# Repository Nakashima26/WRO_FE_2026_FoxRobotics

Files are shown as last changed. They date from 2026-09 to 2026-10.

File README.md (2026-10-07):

# WRO 2026 — Future Engineers | Self-Driving Car

> **Team:** FoxRobotics
> **| Members:** Erick Blanco · Jesse Banda · César Emiliano Ahumada
> **| Coach:** Daniel Millan
> **| Country / Region:** México — Baja California
> **| Season:** 2026

---

## Table of Contents

1. [Vehicle Overview](#1-vehicle-overview)
   - [1.1 Design goals](#11-design-goals) · [1.2 Bill of Materials](#12-bill-of-materials) · [1.3 What changed in v2](#13-what-changed-for-the-international-final-v2)
2. [Mechanical Design & Mobility](#2-mechanical-design--mobility)
   - [2.1 Chassis selection](#21-chassis-selection) · [2.2 Wheels](#22-wheels) · [2.3 Drive system (torque vs. speed)](#23-drive-system-torque-vs-speed-analysis) · [2.4 Steering](#24-steering--rack-and-pinion-with-ackermann-geometry) · [2.5 Custom parts & assembly](#25-custom-parts--assembly) · [2.6 v2 chassis](#26-v2-chassis--shorter-car-pi-on-top)
3. [Power Architecture & Sensors](#3-power-architecture--sensors)
   - [3.1 Power budget](#31-power-budget) · [3.2 Sensor selection and placement](#32-sensor-selection-and-placement) · [3.3 PCB & wiring](#33-pcb--wiring) · [3.4 Raspberry Pi 5](#34-main-computer--raspberry-pi-5-v2)
4. [Software Architecture](#4-software-architecture)
   - [4.1 System overview](#41-system-overview--two-controllers-one-link) · [4.2 Inter-controller protocol ("V2")](#42-inter-controller-protocol-v2) · [4.3 Vision pipeline](#43-vision-pipeline-raspberry-pi--pure_pursuit) · [4.4 Obstacle handling](#44-obstacle-handling-obstacle-challenge) · [4.5 ESP32 state machine](#45-esp32-finite-state-machine-srcesp32purepursuitpurepursuitino) · [4.6 Cascade PID](#46-cascade-pid-always-running-underneath) · [4.7 Startup handshake](#47-startup-handshake) · [4.8 Development status](#48-development-status)
5. [Systemic Thinking & Engineering Decisions](#5-systemic-thinking--engineering-decisions)
   - [5.0 Design constraints](#50-design-constraints) · [5.1 Subsystem interaction map](#51-subsystem-interaction-map) · [5.2 Key engineering trade-offs](#52-key-engineering-trade-offs) · [5.3 Iteration log](#53-iteration-log) · [5.4 Risk analysis](#54-risk-analysis) · [5.5 Failure & Incident log](#55-failure--incident-log)
6. [Testing & Validation](#6-testing--validation)
   - [6.1 How we test](#61-how-we-test) · [6.2 Results to date](#62-results-to-date) · [6.3 Validation matrix](#63-validation-matrix) · [6.4 Pre-run checklist](#64-pre-run-checklist-each-venue) · [6.5 Milestones](#65-milestones) · [6.6 Releases](#66-releases)
7. [How to Build & Run](#7-how-to-build--run)
   - [7.1 Hardware](#71-hardware-requirements) · [7.2 ESP32 firmware](#72-esp32-firmware) · [7.3 Raspberry Pi software](#73-raspberry-pi-software) · [7.4 Calibration](#74-calibration-before-each-venue) · [7.5 Run](#75-run) · [7.6 Autostart & deployment](#76-autostart--deployment)
8. [Repository Structure](#8-repository-structure)
9. [Videos](#9-videos)
10. [Photos](#10-photos)

**Companion document:** [Engineering Journal](ENGINEERING_JOURNAL.md) — the dated, phase-by-phase build log, from the pre-repo design work through today, tied to commits. [§5.3 Iteration log](#53-iteration-log) and [§6.5 Milestones](#65-milestones) are the thematic views of the same history.

---

# 1. Vehicle Overview

<p align="center">
  Isometric view of the vehicle
</p>

Our vehicle is a custom-built autonomous car for the WRO 2026 Future Engineers — Self-Driving Cars challenge. It completes 3 laps around a randomized track, and in the Obstacle Challenge it also detects and correctly passes coloured traffic-sign pillars (**red → keep the pillar on the car's left / pass on its right; green → keep it on the right / pass on its left**) before parking at the end.

The car uses **two controllers working together**: a Raspberry Pi runs the camera vision pipeline (a Raspberry Pi 4 at the national final, a Raspberry Pi 5 for the international final) and the high-level path planner (Pure Pursuit), and an ESP32 runs the real-time control loop, the state machine and all the actuators. They talk over a UART link with a small line-based protocol ("V2"). This split is the central architectural decision of the project and is explained in [Section 4](#4-software-architecture) and [Section 5](#5-systemic-thinking--engineering-decisions).

**Key specifications:**

| Parameter | Value |
|---|---|
| Dimensions | v1: 210 × 140 × 80 mm body, ≈240 mm overall with the extension added to drive out of the parking lot · v2: ≈170 × 130 × 110 mm (168.7 × 128 mm in CAD; height includes the camera ribbon over the top, §2.6) |
| Weight | 564 g |
| Drive type | Rear-wheel drive (RWD) |
| Steering | Ackermann rack-and-pinion, SG90 servo — v2: 53° inner / 37° outer wheel at full lock, ~106% Ackermann (§2.4) |
| High-level controller | Raspberry Pi 5, 16 GB + Active Cooler (vision + Pure Pursuit) — Raspberry Pi 4 Model B until the national final (§3.4) |
| Real-time controller | ESP32 DevKit (FSM, PID, motor & sensor I/O) |
| Inter-controller link | UART @ 115200 baud, line protocol "V2" (see §4.2) |
| Vision | Raspberry Pi Camera, NoIR wide-angle lens (FOV ≈ 120°), processed at 640 × 480; custom lens-shading calibration on the Pi 5 (ERR-03) |
| Distance sensors | HC-SR04 (5V) × 3 — left, right, front — via 5V↔3.3V level shifter · v2: + VL53L1X ToF × 4, in integration (§3.2) |
| IMU | MPU-6050 (gyroscope + accelerometer) · v2: BNO085 with on-chip sensor fusion, in integration (§3.2) |
| Drive motor | v1: N20 DC gear motor (50:1) · v2: Pololu 50:1 12 V gear motor **with encoder** · + 2:1 stage → 100:1 total |
| Motor driver | TB6612FNG |
| Battery | 3S LiPo 11.1 V 2200 mAh |
| Logic power | MINI560 step-down, 5 V |

## 1.1 Design goals

One reliable vehicle that finishes **both** challenges — scoring for completing three laps consistently over completing them fast. Everything below follows from that.

- **Fixed architecture from day one: Raspberry Pi 4 + ESP32.** The Pi does *all* image processing and vision; the ESP32 does *all* peripheral I/O — both sensing and actuation. This split was decided before the first line of code and never revisited.
- **Small footprint for maneuverability.** Comfortably inside the rulebook envelope with ~10 cm of margin on width and length — the car is ≈ 20 × 10 cm, deliberately smaller than the limit so it has room to maneuver in the obstacle field.
- **Mechanically extensible.** The chassis and the PCB were designed so components could be added later without a redesign. This paid off directly: the front ultrasonic — added for the obstacle-round segmented turn (see [§4.5](#45-esp32-finite-state-machine-srcesp32purepursuitpurepursuitino)) — went from idea to mounted-and-wired in under 30 minutes because both the chassis and the PCB already had the space and a spare header.
- **Tight-turn capable.** Rack-and-pinion steering driving both wheels symmetrically ([§2.4](#24-steering--rack-and-pinion-with-ackermann-geometry)) so the car can take the obstacle-round corners without a multi-point turn.
- **Room for a printed differential** so the rear wheels can turn at different speeds through a corner without scrub.
- **Electronics-first packaging.** The chassis was sized around the electronics — the Raspberry Pi 4 above all — and the PCB was then laid out to fit the finished mechanical model, not the other way around.

## 1.2 Bill of Materials

### Custom Manufactured Parts

| ID | Component | Description | Quantity | Supplier | Approximate Cost |
|---|---|---|---|---|---|
| 1 | BaseChasis | Main body of the vehicle. | 1 | Custom made, 3D printed | 1.6 USD |
| 2 | TopShell | Upper part of the vehicle. | 1 | Custom made, 3D printed | 1 USD |
| 3 | Cremallera | Rack used for steering. | 1 | Custom made, 3D printed | 0.1 USD |
| 4 | ServoGearDirection | Pinion for the steering system, directly connected to the servo. | 1 | Custom made, 3D printed | 0.5 USD |
| 5 | LinkageDirection | Linkage between the rack and steering knuckle. | 2 | Custom made, 3D printed | 0.05 USD |
| 6 | SteeringKnuckle | Allows lateral wheel movement for steering. | 2 | Custom made, 3D printed | 0.15 USD |
| 7 | DCsupport | Holds the DC motor in place. | 1 | Custom made, 3D printed | 0.05 USD |
| 8 | RingDifferential | Main driven gear of the differential that transfers power to the axle assembly. | 1 | Custom made, 3D printed | 0.25 USD |
| 9 | PlanetDifferential | Allows torque distribution between both wheels while enabling different wheel speeds during turns. | 2 | Custom made, 3D printed | 0.1 USD |
| 10 | PinionDifferential | Transfers rotational motion from the motor to the differential gear system. | 1 | Custom made, 3D printed | 0.1 USD |
| 11 | SunDifferential | Transfers torque from the differential gears to the wheel axle. | 2 | Custom made, 3D printed | 0.1 USD |
| 12 | CameraBase | Holds the camera frame in place. | 1 | Custom made, 3D printed | 0.1 USD |
| 13 | CameraBack | Rear section of the camera frame. Connects to the CameraBase. | 1 | Custom made, 3D printed | 0.1 USD |
| 14 | CameraFront | Camera frame. | 1 | Custom made, 3D printed | 0.2 USD |
| 15 | UltrasonicSupport | Holds an ultrasonic sensor in place (used for the left, right and front sensors). | 3 | Custom made, 3D printed | 0.3 USD |

---

### LEGO Components

| ID | Component | Description | Quantity | Supplier | Approximate Cost |
|---|---|---|---|---|---|
| 16 | Lego 6135494 | Front wheel axle. | 2 | LEGO | 0.8 USD |
| 17 | Lego 4535768 | Rear wheel axle. | 2 | LEGO | 1 USD |
| 18 | Lego 6121485 | Reduces friction on the rear wheels. | 2 | LEGO | 0.4 USD |
| 19 | Lego 4299389 | Rim for rear wheels. | 2 | LEGO | 1.2 USD |
| 20 | Lego 4184286 | Tires for rear wheels. | 2 | LEGO | 3.5 USD |
| 21 | Lego 6251174 | Rim for front wheels. | 2 | LEGO | 1.2 USD |
| 22 | Lego 6182551 | Tires for front wheels. | 2 | LEGO | 3.82 USD |

---

### Electronics

| ID | Component | Description | Quantity | Supplier | Approximate Cost |
|---|---|---|---|---|---|
| 23 | ESP32 | Real-time controller: sensor I/O, cascade PID, finite state machine, actuator PWM. | 1 | Unit Electronics | 8 USD |
| 24 | Raspberry Pi 5 (16 GB) + Active Cooler + M.2 HAT+ | High-level controller: computer vision and Pure Pursuit path planning. Replaced the Raspberry Pi 4 (60 USD) after the national final; price includes taxes and shipping. | 1 | Official reseller | 410 USD |
| 25 | Mini560 5V | Step-down regulators. v2 uses two: one only for the Raspberry Pi 5, one for the ESP32, servo and sensors (v1 had one for everything). | 2 | Amazon | 12 USD |
| 26 | BNO085 | 9-axis IMU with on-chip sensor fusion (heading at 100 Hz). Replaced the MPU-6050 (3 USD) in v2. | 1 | Local purchase | 27 USD (500 MXN) |
| 38 | VL53L1X | Laser time-of-flight distance sensors — front, left, right and rear (v2). | 4 | Local purchase | 27 USD total (500 MXN) |
| 27 | HC-SR04 | Ultrasonic distance sensors — left, right (wall following) and front (obstacle-round cornering). | 3 | Unit Electronics | 10.5 USD |
| 28 | Level Shifter | Logic-level converter for the 5 V HC-SR04 echo lines into the 3.3 V ESP32. | 1 | Unit Electronics | 7 USD |
| 29 | Driver TB6612FNG | Motor driver controlling speed and direction of the DC drive motor. | 1 | Unit Electronics | 5 USD |
| 30 | RaspiCamera V2 | Camera module used for computer vision. Came with both ribbon cables: 15-pin for the Raspberry Pi 4 and 22-to-15-pin for the Raspberry Pi 5. | 1 | Amazon | 10 USD |
| 31 | Custom PCB | Power distribution and all signal connections. v1: single board (5 USD); v2: two-floor board, in design — price pending. | 1 | JLCPCB | 5 USD (v1) |

---

### Power System

| ID | Component | Description | Quantity | Supplier | Approximate Cost |
|---|---|---|---|---|---|
| 32 | Ovonic 2200mAh 3S | 3-cell LiPo battery powering the robot's electronics and drive system. | 1 | E-Bay | 13 USD |

---

### Actuators

| ID | Component | Description | Quantity | Supplier | Approximate Cost |
|---|---|---|---|---|---|
| 33 | Pololu 50:1 12 V gear motor with encoder | Drive motor; the encoder measures speed and distance. Replaced the N20 50:1 (6 USD) in v2. | 1 | Pololu | 20 USD |
| 34 | SG90 Servo | Micro servo motor used for steering control. | 1 | Unit Electronics | 6 USD |

---

### Fasteners

| ID | Component | Description | Quantity | Supplier | Approximate Cost |
|---|---|---|---|---|---|
| 35 | M3 Screws | Used for structural assembly and component mounting. | 23 | Local Hardware Store | 1 USD |
| 36 | M3 Nuts | Used to secure structural and electronic components. | 1 | Local Hardware Store | 0.05 USD |
| 37 | M2 Nuts | Used to secure servo motor and servo pinion | 3 | Local Hardware Store | 0.15 USD |

### Total Estimated Cost

| Version | Total |
|---|---|
| v1 — national final | ~155 USD |
| v2 — international final | **~576 USD** + v2 PCB (pending) |

**Where the increase comes from:** +410 USD Raspberry Pi 5 bundle, +27 BNO085, +27 VL53L1X ×4, +20 encoder motor, +6 second regulator; −69 USD for the parts that left the car (Raspberry Pi 4, MPU-6050, N20). About 85% of the increase is the Raspberry Pi 5, justified by the profiling in [§3.4](#34-main-computer--raspberry-pi-5-v2): 40 fps vs ~15 fps, no thermal throttling.

## 1.3 What changed for the international final (v2)

After winning the national final (2026-09-19, release [`v1.0-nacional`](docs/releases.md)) we reworked the parts of the car that were limiting it. Each change has its own section with the numbers behind it.

| Area | v1 (national final) | v2 | Why | Details |
|---|---|---|---|---|
| Steering geometry | Anti-Ackermann: the outer wheel steered *more* than the inner one (39.5° inner / 42.8° outer) | Ackermann corrected: rack joints 43 → 47 mm apart, tie rods 18.13 mm | Both front wheels now roll around the same turning center instead of fighting each other | [2.4](#24-steering--rack-and-pinion-with-ackermann-geometry) |
| Steering pinion | Module 1, 14 teeth | Module 1, **19 teeth**; servo moved 2.5 mm away from the rack | Same servo travel moves the rack 36% further: ~37° → **53°** on the inner wheel (measured in CAD) | [2.4](#24-steering--rack-and-pinion-with-ackermann-geometry) |
| Main computer | Raspberry Pi 4 | **Raspberry Pi 5, 16 GB** + Active Cooler | The Pi 4 was compute-bound at 14–18 fps and hit thermal throttling at 84 °C; the Pi 5 runs the same pipeline at ~40 fps at 52 °C | [3.4](#34-main-computer--raspberry-pi-5-v2) |
| Chassis layout | ≈24 cm long; Raspberry Pi enclosed in the center; motor perpendicular to the rear axle (bevel gears) | **≈17 cm long**; battery in the center where the Pi was; Pi 5 on top, open to the air; motor parallel to the axle (spur gears, same 2:1) | Tighter turns and more room to dodge and park; the enclosed Pi overheated (84 °C, throttling) | [2.6](#26-v2-chassis--shorter-car-pi-on-top) |
| Distance sensing | 3 × HC-SR04 only | 3 × HC-SR04 **+** 4 × **VL53L1X** ToF (front, left, right, rear), cross-checked against each other | Each sensor type fails differently against the black walls: the ultrasonic gives phantom echoes, the ToF can lose a dark wall. Using both lets each one veto the other's known failure | [3.2](#why-both-ultrasonic-and-tof) |
| Drive motor | N20 50:1, open-loop | **Pololu 50:1 with encoder** (mounted; speed loop pending) | Maneuvers changed with battery voltage; the encoder gives measured speed and distance | [2.6](#26-v2-chassis--shorter-car-pi-on-top) |
| IMU | MPU-6050, gyro rate integrated on the ESP32 | **BNO085**, fused heading computed on the sensor (UART-RVC, 100 Hz) | Integrated heading was 6.5% low over a run and carried a −7.5° bias after every corner maneuver | [3.2](#bno085-imu-v2-in-integration) |
| Power | One 5 V regulator for everything | **Two** regulators: one only for the Raspberry Pi 5 | Servo current spikes must not sag the Pi's supply; the Pi 5 draws more | [3.1](#v2-power-budget) |
| PCB | One board | **Two-floor** board: power floor + logic floor (in design) | The shorter chassis has less area, and four ToF + BNO085 need new connectors | [3.3](#v2-pcb--two-floor-board-in-design) |
| Camera color | Fixed white-balance gains only (Pi 4) | Lens-shading table calibrated for our lens + gains, as a project tuning file | The new image processor of the Pi 5 showed a magenta ring at the frame edges, close to the pink parking walls and red pillars | [ERR-03](#err-03--wide-angle-noir-lens-put-a-red-cast-on-every-frame) |
| Documentation | One README | + [releases](docs/releases.md), [test record](docs/testing.md), [engineering log](docs/engineering-log.md) (ERR-10 onward) | One release per event; every failure tied to a run number and a commit | §6 |

---

# 2. Mechanical Design & Mobility

### 2.1 Chassis selection

The chassis was designed from scratch to fit all the components we needed for competition. We printed it in red and black SUNLU PLA on a Bambu Lab A1, keeping the structure as light as possible without sacrificing the rigidity the drivetrain and electronics require.

For wheel transmission shafts, we used LEGO axles throughout: part 6135494 for the front and part 4535768 for the rear. This wasn't an aesthetic choice — LEGO axles have much better dimensional consistency than fully printed shafts, which flex under load and cause alignment issues. We also added LEGO bushings (6121485) to the rear axle to cut down on friction between moving parts.

| Component | Material / Part | Purpose |
| --- | --- | --- |
| Chassis | SUNLU PLA | Main robot structure |
| Front Axles | LEGO 6135494 | Power transmission |
| Rear Axles  | LEGO 4535768 | Rear drivetrain support |
| Bushings | LEGO 6121485 | Friction reduction |
| Printer | Bambu Lab A1 | Manufacturing process |

We used PLA because it prints fast, doesn't warp like ABS, and is stiff enough for indoor competition conditions. PETG has better impact resistance and ABS handles heat better, but neither of those properties matters much for a robot running on a flat mat indoors. What did matter was being able to iterate quickly and get consistent parts, and PLA delivered on both.

### 2.2 Wheels

We tested several wheel options before settling on LEGO parts. The rear wheels use rim 4299389 with tire 4184286, and the front uses rim 6251174 with tire 6182551. Both have a 43 mm outer diameter, which keeps the ride height even front to rear.

Since the drivetrain already uses LEGO axles, LEGO-compatible rims were the obvious fit — they mount directly without adapters, which removes a potential source of wobble at the wheel interface.

The 43 mm diameter was also validated against our motor RPM target. At our gear ratio, this diameter puts normal operation in the 40–70% PWM range, which gives us enough resolution for smooth speed control. A noticeably larger wheel would push operating duty cycles above 85% and compress the usable throttle range.

We ran the car at full throttle on the competition mat surface and saw no detectable slip at the rear. The LEGO rubber compound grips the white matte WRO field without any prep needed.

### 2.3 Drive system (torque vs. speed analysis)

The main drive is an N20 DC motor with a 50:1 internal gearbox — compact at 12 × 10 × 26 mm and still enough torque for a ~1.5 kg vehicle. Between the motor output shaft and the differential, we added a 2:1 LEGO gear stage, bringing the total drivetrain reduction to **100:1** and estimated rear axle torque to about 1.76 kg·cm.

**Why 100:1 and not just 50:1?**

We ran the 50:1 configuration first. It was faster, but corner exits were inconsistent — the rear wheels would occasionally lose traction under acceleration, causing yaw disturbances the PID couldn't fully catch. At 100:1, top speed dropped but torque delivery became smooth and predictable all the way through the speed range. Corner exits became repeatable, which turned out to be a prerequisite for reliable PID tuning.

The ratio also keeps the motor in its efficient RPM band during most of the run, which matters because the motor shares a power source with the logic rail.

The car completes all three Open Challenge laps in about 12 seconds at just 60% motor speed. That headroom is useful if we need to push speed in later iterations.

**The takeaway:** we prioritized consistency over raw speed. A robot that reliably finishes 3 laps scores more than one that's faster but unpredictable.

### 2.4 Steering — rack-and-pinion with Ackermann geometry

Steering is controlled by an SG90 servo connected to both front knuckles through a rack-and-pinion mechanism with symmetric tie rods.

**Mechanism specs (v1, national final):**

| Parameter | Value |
|---|---|
| Servo | SG90 (0°–180° range) |
| Firmware straight-ahead trim | 80° (servo-horn spline offset; `centroServo` in firmware) |
| Pinion | Module 1, 14 teeth |
| Pinion pitch diameter | 14 mm (dp = m × z = 1 × 14) |
| Pinion outer diameter | 16 mm (dp + 2×addendum = 14 + 2) |
| Rack | Module 1, 11 teeth, 27.5 mm total travel |
| Rack displacement per servo degree | 0.1222 mm/° |
| Transmission ratio | 2.50° servo : 1° wheel |
| Geometric wheel steering range | ±43° from center |
| Firmware-clamped servo command | 20°–150° (≈ ±35° usable at the wheel) |

**Kinematic analysis:**

The 14 mm pitch diameter gives a pitch circumference of 43.98 mm. Each degree of servo rotation moves the rack 0.1222 mm. At 90° per side from center, the rack travels 11.00 mm per side — producing ±43° at the front wheels.

The outer diameter of 16 mm confirms the module (d_outer = dp + 2×m = 14 + 2 = 16 mm).

The 2.50:1 ratio reduces steering sensitivity at the wheel, which gives the inner control loop finer resolution at its update rate. A lower ratio would make steering response too abrupt.

The firmware never commands the full mechanical range: `escribirServo()` is clamped to 20°–150° (about ±35° at the wheel) so a saturated control output can't drive the rack into its physical end stop. That still clears the tightest Open-Challenge corridor (600 mm) and the maneuvering the Obstacle Challenge needs.

**Why rack-and-pinion over a direct servo arm?**

A direct arm only controls one wheel directly. The opposite knuckle, linked by a fixed-length tie rod, gets an angle that's geometrically correct only at center — producing toe error everywhere else. The rack pushes both tie rods symmetrically, so both wheels get the right angle at every steering position. Combined with the Ackermann geometry of the knuckles, each wheel tracks its own correct turning radius. No lateral scrub, and steering response is linear across the full range.

#### v2 redesign (October 2026) — Ackermann fix and a bigger pinion

In v2 we redesigned this mechanism because of two problems: the geometry was **anti-Ackermann**, and the car **could not turn tightly enough**. We simulated the linkage in Python with the exact CAD dimensions (the model matched the CAD within ~1°) before reprinting anything.

**Geometry reference** (top view, wheels straight, measured in SolidWorks):

| Parameter | Value |
|---|---|
| Kingpin track T (distance between the two knuckle pivots) | 60 mm |
| Wheelbase L (front kingpin line → rear axle) | 112.85 mm |
| Knuckle steering arm (pivot → tie-rod joint) | 12.49 mm, pointing ~43° outward and backward |
| Rack joints behind the kingpin line | 18.94 mm |
| Servo swing actually used | ±71° (measured from the rack travel, not the nominal ±90°) |

##### Problem 1 — anti-Ackermann (fixed)

In a turn, the inner wheel follows a smaller circle than the outer wheel, so it must steer **more**. Correct (100%) Ackermann is reached when

  **cot(δ_outer) − cot(δ_inner) = T / L = 0.532**

and the axis lines of both front wheels cross on the rear axle line.

In v1 the rack joints were only 28.5 mm apart with 26 mm tie rods. We simulated the linkage in Python with the exact CAD dimensions, and the model matched the CAD within ~1°. At full travel the car steered **39.5° on the inner wheel and 42.8° on the outer wheel**: the outer wheel was steering *more* than the inner one. The two front wheels were trying to turn around different centers, so one of them always dragged sideways. That cost traction and current in every corner, and the car turned wider than the servo command implied.

Because the knuckles had to stay as they were (a new knuckle means a new arm, and the rack position is fixed by the chassis), we only changed **the spacing between the rack joints** and **the tie-rod length**. Those two values must change together: for the wheels to point straight with the rack centered, the tie rod must be

  **linkage = √( (38.66 − spacing/2)² + 9.94² )**  (mm, center to center)

| Rack joint spacing | Tie rod | Ackermann at 30° | 40° | 45° | 50° | 55° |
|---|---|---|---|---|---|---|
| 28.5 (v1) | 26.0 | anti-Ackermann | | | | |
| 43.0 (intermediate) | 19.83 | 51% | 62% | 69% | 76% | 84% |
| **47.0 (v2)** | **18.13** | 76% | **89%** | **95%** | **102%** | 110% |
| 50.0 | 16.89 | 99% | 111% | 117% | 124% | 131% |

*(Percentage = how much of the ideal inner/outer difference the linkage achieves. Below 100% the outer wheel steers slightly too much; above 100% it steers too little.)*

**Why 47 mm:** with a fixed knuckle, Ackermann cannot be exact over the whole range, because the percentage grows as the wheels turn. We chose the spacing that is closest to 100% in the 40°–50° range, which is where the car actually turns at corners and during parking. At small angles the error is under 0.7°, so it does not matter there. Each 0.1 mm of tie-rod error toes a wheel by ~0.5°, so the printed linkages are trimmed in 0.05–0.1 mm steps until the wheels are straight.

##### Problem 2 — turning radius (bigger pinion)

The steering angle depends almost only on **how far the rack moves**, and with the v1 pinion that was **±8.7 mm**: only ~37° on the inner wheel. We looked at three options: shorter knuckle arms, moving the rack, and a bigger pinion. The bigger pinion was the only one that needed no new chassis or knuckles.

| | v1 | **v2** |
|---|---|---|
| Pinion | Module 1, 14 teeth | **Module 1, 19 teeth** (20° pressure angle) |
| Pitch / outer diameter | 14 / 16 mm | **19 / 21 mm** |
| Rack travel per servo degree | 0.122 mm/° | **0.166 mm/°** |
| Rack travel at ±71° servo | ±8.7 mm | **±11.8 mm** |
| Inner / outer wheel at full lock | ~37° / ~32° (with 43 mm spacing) | **53.1° / 37.0°** (measured in the CAD assembly; the linkage model predicted ~50° / ~37°) |
| Turning radius at the rear-axle center (L / tan δ_inner + T/2) | ~208 mm (v1: 147 mm wheelbase, 39.5°) | **~115 mm** (v2: 113 mm wheelbase) — −45% |
| Ackermann at full lock | anti-Ackermann | **~106%** (ideal outer for 53.1° inner = 37.9°, measured 37.0°) |

- **Servo position.** The pitch radius grows from 7 to 9.5 mm, so the servo axis moved **2.5 mm away from the rack** with a spacer on its mount. The rack and the tie-rod joints stay at the same height, so the linkage geometry above is not affected.
- **Pinion profile.** We generated the involute tooth profile with our own script ([`Mecanica/Engranes/gen_pinon.py`](Mecanica/Engranes/gen_pinon.py)) and exported it as a single closed DXF contour that we extrude in SolidWorks. It includes 0.10 mm of backlash for 3D printing.
- **Toggle limit.** The linkage would lock (arm and tie rod aligned) at around 16 mm of rack travel. If the servo ever reached a true ±90°, the 19-tooth pinion could push the rack to ±14.9 mm. The intended mechanical stop is the knuckle touching the chassis before that point, and the servo output is also clamped in software.
- **Servo load.** The bigger pinion needs ~1.36× more servo torque for the same rack force. It also loses some angular resolution, which is still fine for an SG90 in a 0.5 kg car. The servo must not be left stalled against the stop, because it heats up and drags down the 5 V rail.

**Servo calibration.** The servo-to-wheel relation is no longer linear: near full lock the wheels turn faster per servo degree. The servo map and the steering gains in the ESP32 firmware are recalibrated on the assembled car (pending).

### 2.5 Custom parts & assembly

Every structural part is 3D-printed in SUNLU PLA on a Bambu Lab A1. The mechanical model was built first; the PCB was then laid out to fit it. Editable SolidWorks parts are in [`models/CAD/`](models/CAD/), printable meshes in [`models/STL/`](models/STL/), isometric renders in [`models/renders/`](models/renders/).

<p align="center">
  Full vehicle CAD assembly
</p>

| Render | Part | Function / design note |
|---|---|---|
| BaseChasis render | **BaseChasis** | Main structure. Sized around the electronics (Raspberry Pi 4 first); carries the PCB, steering, drivetrain and every sensor mount. |
| TopShell render | **TopShell** | Top cover — closes the electronics bay and protects the wiring. |
| ServoGearDirection render | **ServoGearDirection** | Pinion pressed onto the SG90 output shaft — module 1, 14 teeth (19 teeth in v2, [§2.4](#24-steering--rack-and-pinion-with-ackermann-geometry); profile generated by [`Mecanica/Engranes/gen_pinon.py`](Mecanica/Engranes/gen_pinon.py)). |
| Cremallera render | **Cremallera** (rack) | Module 1, 11 teeth, 27.5 mm travel. Converts servo rotation into lateral travel for the tie rods. |
| LinkageDirection render | **LinkageDirection** ×2 | Tie rods from the rack ends to the steering knuckles — symmetric, so both wheels get the correct angle at every rack position. |
| SteeringKnuckle render | **SteeringKnuckle** ×2 | Front-wheel pivots; their geometry sets the Ackermann steering angles. |
| Differential render | **Differential** (Ring / Planet ×2 / Pinion / Sun) | Printed open differential — lets the rear wheels turn at different speeds through a corner. |
| DCsupport render | **DCsupport** | Mounts the N20 gear motor to the chassis. |
| UltrasonicSupport render | **UltrasonicSupport** ×3 | Two identical side mounts; one slightly smaller front mount, added later for the obstacle-round segmented turn. |
| Camera cage render | **CameraHold** | Structure in charge of holding the camera. Sets the fixed ~20° downward tilt the BEV homography is calibrated against ([§3.2](#32-sensor-selection-and-placement)). |

#### Assembly order

1. **Chassis base** — the reference part everything mounts to.
2. **Steering** — press the pinion onto the servo and seat the servo in the chassis; slide in the rack; link each rack end to a SteeringKnuckle with a LinkageDirection tie rod; fit the knuckles and the front LEGO axles.
3. **Drivetrain** — N20 motor into the DCsupport; assemble the printed differential; rear LEGO axles with bushings.
4. **Sensor mounts** — the two side UltrasonicSupports (identical) and the smaller front one; the camera cage (base + back + front) with the camera.
5. **Electronics** — PCB onto the chassis bosses; wire the Pi 4, ESP32, the three HC-SR04 (through the level shifter), the MPU-6050, the TB6612 + motor, the servo, and the start button + status LED.
6. **TopShell** — close the bay.

All fasteners are M3 (M2 nuts on the servo horn and pinion).

### 2.6 v2 chassis — shorter car, Pi on top

*Status: designed in SolidWorks, being printed. Final dimensions and weight will be measured on the printed car.*

For the international final we rebuilt the chassis around two problems we kept seeing at the national final:

1. **The car was long for the obstacle field.** The body was 210 mm, but it reached ≈24 cm overall with an extension we added so the car could drive out of the parking lot comfortably. At that length every dodge swept a lot of floor, and the parking maneuver had little room in the lot.
2. **The Raspberry Pi overheated.** It sat enclosed in the middle of the chassis. With the remote-view client running it reached **84 °C** and throttled its CPU ([ERR-27](docs/engineering-log.md#err-27--the-remote-desktop-client-overheated-the-pi-4)), which lowered the vision frame rate.

**What we changed**

| Change | How | Why |
|---|---|---|
| **Motor parallel to the rear axle** | The drive motor now lies along the axle and drives the differential through **spur gears** (module 1, 15-tooth pinion on the motor's D-shaft, 30-tooth ring on the differential) instead of the perpendicular bevel pair | A motor perpendicular to the axle adds its whole length to the car. Lying along the axle, it adds almost nothing. |
| **Battery in the center** | The 3S pack sits crosswise in a side-loading tunnel, in the space the Raspberry Pi used to take | The heaviest part ends up in the middle and low, which balances the load front to rear. The side tunnel makes battery swaps quick. |
| **Raspberry Pi 5 on top** | The Pi moves from the enclosed center bay to the top of the car | The Active Cooler needs free air. Enclosed, the Pi recirculated its own hot air. On top, it also stays reachable for the camera cable and the SSD. |
| **Encoder motor** | Pololu 50:1 12 V gear motor with a quadrature encoder replaces the plain N20; same 50:1 ratio | Motor speed is open-loop today, so maneuvers change with battery voltage ([ERR-11](docs/engineering-log.md#err-11--a-fresh-battery-over-rotates-the-dodges)). The encoder lets the ESP32 hold a speed and measure distance, as the rules' reference build suggests. *Mounted; firmware integration pending.* |
| **Overall length ≈24 cm → ≈17 cm** (width 128 mm) | Result of the changes above | See below |

**Why a shorter car turns tighter.** For Ackermann steering, the radius of the path at the center of the rear axle is

  **R = L / tan(δ_inner) + T/2**

where L is the wheelbase and T the kingpin track (60 mm). Shortening L shrinks R directly, at the same steering angle. With the v2 steering (53° inner wheel, [§2.4](#24-steering--rack-and-pinion-with-ackermann-geometry)) and the v2 wheelbase of **≈113 mm** (CAD), R ≈ **115 mm**. The v1 car had a wheelbase of ≈147 mm (measured) and ~40° of steering, so R ≈ **208 mm**. The turning radius is therefore **≈45% smaller**: about half from the shorter wheelbase, about half from the bigger steering angle. A smaller radius means a dodge needs less lateral room, the stop-and-turn corner maneuver needs less space ahead of the front wall, and the car fits the parking lot with more margin.

**The drivetrain keeps its ratio.** The old bevel pair was 36:18 = 2:1, and the new spur pair is 30:15 = 2:1. The total reduction stays at **100:1**, so the torque and speed analysis of [§2.3](#23-drive-system-torque-vs-speed-analysis) still holds. Spur gears are also easier to print accurately and to align than bevel gears. We checked the tooth strength with the Lewis bending equation (8 mm face, at the N20's stall torque): ≈5.7 MPa, roughly 9× below the strength of printed PLA. It is re-checked with the stall torque of the encoder motor. The gear center distance is designed at 22.6–22.7 mm (22.5 mm nominal) to leave printing clearance. The involute profiles are generated by our own script and exported as DXF; SolidWorks Standard has no gear generator.

**What stayed about the same, on purpose:** the height of the chassis, for stability in fast turns (the v2 car is ≈110 mm tall, but only the camera ribbon over the top reaches that);  the LEGO axles and wheels ([§2.1](#21-chassis-selection), [§2.2](#22-wheels)); and the camera height and angle, so the bird's-eye-view calibration concept carries over (it is re-calibrated on the new mount).

---

# 3. Power Architecture & Sensors

### 3.1 Power budget

The whole vehicle runs off an Ovonic 2200mAh 3S LiPo. Power splits two ways: the motor driver takes battery voltage directly for the DC motor, and everything else goes through a MINI560 step-down converter producing a stable 5V at up to 5A.

| Rail | Source | Consumers | Max Current Draw |
|---|---|---|---|
| 5V Logic | MINI560 Step-Down Converter | Raspberry Pi 4 + RaspiCam V2, ESP32, HC-SR04 ×3, MPU6050, SG90 | ~4.0 A |
| Battery / Main Power | Ovonic 2200mAh 3S LiPo | Entire vehicle power distribution | ~35 A discharge capability |
| Motor Power | Motor Driver directly from 3S LiPo | DC drive motor | ~1.6 A peak |
| 3.3V Internal | ESP32 internal regulator | I²C communication and internal ESP32 logic, Level Shifter | ~200 mA |

The Ovonic battery is rated 120C continuous, which is theoretically 264 A. We're drawing about 4.5 A peak — under 2% of its discharge capability. There's no shortage of headroom here.

The Raspberry Pi and the ESP32 share the 5 V rail but the DC motor is fed straight from the battery through the TB6612FNG, so stall-current spikes on the motor never sag the logic supply.

#### v2 power budget

*Design values from the component datasheets and the Raspberry Pi documentation. Each rail will be measured with an inline meter on the assembled v2 car, and the measured values will replace these.*

The Raspberry Pi 5 draws more than the Pi 4 and is sensitive to voltage drops: when its supply sags it throttles the CPU, which directly lowers the vision frame rate. We already saw this on the Pi 4 when it was fed through Dupont jumpers (`throttled=0x50005`, CPU down to 600 MHz, [ERR-08](#err-08--raspberry-pi-undervoltage-from-undersized-power-wiring)). v2 therefore has **two 5 V regulators**: one only for the Raspberry Pi 5, and one for everything else. The servo's current spikes can no longer pull down the Pi's supply.

| Rail | Load | Typical | Design peak | Basis |
|---|---|---:|---:|---|
| **5 V-A** (Mini560 #1, 5 A) | Raspberry Pi 5 under vision load | 1.5 A | 2.5 A | 0.8 A bare-board active (Raspberry Pi docs) + 4 cores busy; peak covers load spikes |
| | Camera v2 | 0.25 A | 0.25 A | Camera module figure |
| | Active Cooler fan | 0.05 A | 0.1 A | Fan at full speed above 75 °C |
| | **Rail total** | **1.8 A** | **2.85 A** | 57% of the regulator's 5 A at peak |
| **5 V-B** (Mini560 #2, 5 A) | ESP32 (radio off) | 0.08 A | 0.25 A | Datasheet |
| | SG90 servo | 0.25 A | 0.70 A | Running current; peak = stall |
| | HC-SR04 × 3 | 0.045 A | 0.045 A | 15 mA each |
| | VL53L1X × 4 | 0.08 A | 0.16 A | ~20 mA each ranging, 40 mA peak |
| | BNO085 | 0.013 A | 0.013 A | Datasheet operating figure |
| | **Rail total** | **0.47 A** | **1.17 A** | 23% of the regulator at peak |
| **Battery 11.1 V** | Drive motor via TB6612 | — | 1.6 A | Peak measured on v1 (N20); to be re-measured with the encoder motor |
| **5 V-B** | Motor encoder | 0.01 A | 0.01 A | Hall-effect encoder |

**Battery current.** With ~90% regulator efficiency, the two 5 V rails at design peak draw 5 V × (2.85 + 1.17) A / 0.9 ≈ 22 W, which is ≈2.0 A from the 11.1 V pack. Adding the motor's 1.6 A gives **≈3.6 A worst case**. The 2200 mAh pack would last over 35 minutes even at that worst case, against a 3-minute round, so **capacity is not the constraint. Voltage is.** A freshly charged pack makes the motor ~17% stronger in low-PWM maneuvers ([ERR-11](docs/engineering-log.md#err-11--a-fresh-battery-over-rotates-the-dodges)), so we race inside an 11.70–12.15 V window.

**Heat.** At its typical 1.8 A, regulator #1 loses about 1 W at 90% efficiency. It is mounted in the airflow of the Pi on top of the car.

**Check before every session:** `vcgencmd get_throttled` must read `0x0` under full vision load.

### 3.2 Sensor selection and placement

| Sensor | Purpose | Placement | Notes |
|---|---|---|---|
| Raspberry Pi Camera Module V2 | Lane, corner-line and pillar detection | Front-center, ~20° downward tilt | Main vision system, OpenCV on the Pi |
| HC-SR04 (left) | Left wall distance | Left side of the chassis | Feeds the wall-centering PID |
| HC-SR04 (right) | Right wall distance | Right side of the chassis | Feeds the wall-centering PID |
| HC-SR04 (front) | Distance to the wall ahead when approaching a corner | Front bumper, facing forward | Obstacle round only — triggers the CRUCERO → MANIOBRA sequence |
| MPU-6050 *(v1)* | Heading integration during cornering and recovery | Center of chassis | Gyro Z integrated into `anguloGyro`, echoed back to the Pi |
| BNO085 *(v2, in integration)* | Fused heading at 100 Hz | Center of chassis, near the rotation axis | Replaces the MPU-6050; heading computed on the sensor |
| VL53L1X ToF ×4 *(v2, in integration)* | Near-field distance (≤ ~80 cm) with a software-set field of view | Front, left, right and rear, ~50 mm high | Cross-checked against the HC-SR04 — see [Why both](#why-both-ultrasonic-and-tof) |

#### Camera system

The camera handles lane geometry (via a bird's-eye-view transform), the orange corner-line markers, and red/green pillar detection. Image processing runs on the Raspberry Pi (Pi 4 → Pi 5 in v2) with OpenCV in real time and drives the Pure Pursuit planner.

It is mounted front-center with a ~20° downward tilt. We tested a horizontal mount first, but that captured too much background, which slowed detection and added noise. Tilting it down focuses the field of view on the track and the obstacle zone, which cut both false positives and computational load. The exact tilt is baked into the bird's-eye-view homography during calibration (see §4.3), so the mount must not move after calibration.

The lens is a wide-angle **NoIR** unit (~120° FOV), chosen over the original ~63° lens so the camera sees far enough ahead to react to a pillar and read the corner on the same frame. The wide lens ships without an IR-cut filter, which gave the raw image a heavy red cast and broke every HSV mask. The libcamera capture pipeline pins white-balance instead of letting it float — `libcamerasrc awb-enable=false colour-gains=<1.2,1.5>` — so the correction holds across venue lighting, and the pillar HSV ranges were re-tuned on the corrected image (see [ERR-03](#err-03--wide-angle-noir-lens-put-a-red-cast-on-every-frame)).

**v2 (Raspberry Pi 5):** fixed gains alone are not enough. The lens also needs its own **lens-shading table** (ALSC), otherwise the edges of the frame turn magenta. We calibrate that table from photos of a white sheet with the official Raspberry Pi tuning tool and ship it as a project tuning file, [`src/RASPI/cam/camera_tuning/`](src/RASPI/cam/camera_tuning/README.md). Result on a white sheet: R/G and B/G = 1.00 at the center **and** at all four corners (they were 1.3–1.4 at the corners).

#### HC-SR04 ultrasonic sensors

The left and right sensors drive lateral positioning and wall following. The **front** sensor was added for the Obstacle Challenge: because that round uses a segmented, stop-and-maneuver turn instead of a continuous arc (see §4.5), the car needs to know how far it is from the wall ahead so it can decide *when* to stop cruising and *which* maneuver (forward arc or reverse pivot) to run.

We originally tested VL53L0X time-of-flight sensors. On paper they win — ±3 mm accuracy versus ±15 mm for the HC-SR04, and a narrower beam. In practice, the black competition walls absorbed their 940 nm IR signal and consistently returned out-of-range readings at 300 mm. The HC-SR04 reflects off any surface regardless of color. We went with reliability over precision and made up the accuracy difference with software filtering (EMA on all three channels, plus a 5-sample median on the front channel to reject spikes before they can trigger a maneuver).

#### MPU-6050 IMU

The MPU-6050 gives heading and rotation data during cornering and recovery. The gyro Z axis is integrated each loop into `anguloGyro`, with a 1°/s deadband to suppress MEMS thermal drift on straights. On startup the firmware averages several hundred stationary samples to compute the gyro bias (`calcGyroOffsets`); if that offset comes back unusually large the firmware halves the integration scale as a safety net. The integrated heading is also sent back to the Pi in every acknowledgement so the vision side can dead-reckon obstacle positions (see §4.4).

#### BNO085 IMU (v2, in integration)

**Why replace the MPU-6050.** The MPU-6050 only gives a gyro *rate*. The ESP32 integrates it once per main loop, with a 1°/s deadband and a bias measured at boot. Our logs show what that costs:
- The integrated heading over a full run came out **6.5% low**: ≈1010° for the 1080° of 12 corners ([§6.3](#63-validation-matrix) #6).
- After every corner maneuver the heading carried a constant **−7.5° ± 0.9°** bias ([ERR-23](docs/engineering-log.md#err-23--systematic-heading-offset-after-every-corner)).
- The integration accuracy depends on how regular the main loop is, and the loop is busy with sensors and serial traffic.

The **BNO085** is a 9-axis sensor (gyroscope, accelerometer and magnetometer) that runs the sensor fusion on its own processor, with continuous bias calibration, and outputs a finished heading.

**How we connect it.** We use its **UART-RVC** mode. The sensor sends a 19-byte packet with yaw, pitch, roll and acceleration every 10 ms (100 Hz) over a single wire: BNO TX → ESP32 GPIO 25. Each packet carries a checksum. We chose this mode because it needs no driver library, keeps the IMU off the I²C bus that the four ToF sensors share, and lets the ESP32 just read the latest heading instead of integrating it. The test sketches [`BnoRvcTest`](src/ESP32/BnoRvcTest/BnoRvcTest.ino) and [`TofBnoTest`](src/ESP32/TofBnoTest/TofBnoTest.ino) report the packet rate, the longest gap, lost packets and checksum errors.

**Acceptance before it gets control** (log-only next to the MPU-6050 first):
- ≥ 99% of packets at ~100 Hz on the car, with the motor running.
- Total rotation over 12 corners within ±1% of 1080° (the MPU-6050 was 6.5% low).
- **Heading unchanged while the motor runs at standstill.** The BNO085 includes a magnetometer, and a magnetometer sitting a few centimeters from a motor and a LiPo pack can be pulled by their magnetic fields. If this test shows drift with the motor on, we switch to the sensor's *game rotation vector* (gyro + accelerometer only, no magnetometer) over I²C, at the cost of using its driver library.

#### VL53L1X time-of-flight array (v2, in integration)

**Layout:**

| Sensor | Position | Use | XSHUT pin (ESP32) | I²C address |
|---|---|---|---|---|
| Front | Front bumper | Distance to the wall ahead: corner approach and the forward/reverse maneuver choice | GPIO 0 | 0x30 |
| Left | Left side | Distance to the side wall | GPIO 15 | 0x31 |
| Right | Right side | Distance to the side wall | GPIO 5 | 0x32 |
| Rear | Rear bumper | Reverse maneuvers: leaving the lot, reverse pivots and parking, which are blind today | GPIO 4 | 0x33 |

All four share the I²C bus (SDA 21, SCL 22) and all start at the same factory address (0x29). At boot the ESP32 holds every sensor off with its XSHUT pin, then turns them on one by one and gives each a new address. Test sketches: [`TofTest4`](src/ESP32/TofTest4/TofTest4.ino) (4 sensors), [`TofId`](src/ESP32/TofId/TofId.ino) (tells an L0X from an L1X).

#### Why both ultrasonic and ToF

The inner walls of the WRO field are **black**, and that is the hardest surface for a distance sensor. The two sensor types fail against it in **different, recognizable ways**, so we keep both and let each one catch the other's failure:

| | HC-SR04 ultrasonic | VL53L1X time-of-flight |
|---|---|---|
| Black wall | Sound reflects regardless of color ✔ | The black surface absorbs most of the 940 nm infrared. The return is weak: the reading drops out, or the range becomes wrong. Our VL53L0X lost the wall past ~70 cm ([ERR-01](#err-01--vl53l0x-lost-the-black-wall-past-70-cm)), and other teams report ~80–100 cm usable with the L1X ✘ |
| False readings | The echo returns from anything inside a wide acoustic lobe, including the side wall at a grazing angle, plus multipath reflections. The front sensor reported a wall that wasn't there in ~20% of straight-line frames ([ERR-19](docs/engineering-log.md#err-19--phantom-echoes-from-the-front-ultrasonic)) ✘ | An optical cone with no echoes. Its size is set in software (region of interest), so it can be made to look only at the wall ✔ |
| Range | Usable to ~119 cm with our timeout | Near field only (≤ ~80 cm) on a black wall |
| Speed | One ping at a time, since sensors that fire together hear each other | 20 Hz each, all four in parallel |

**Planned cross-check rule.** It runs log-only first, recorded next to the current behavior, before it gets control:
- A ToF reading counts only if its range status is valid, it is ≤ 80 cm, and it is stable for 2 readings.
- **Front:** if the two disagree by more than 15 cm and the ToF reading is valid, trust the ToF; the known failure on that side is the ultrasonic phantom. If the ToF is invalid or out of range, use the ultrasonic; the known failure there is a black-wall dropout.
- **Sides:** if the ToF says "no wall" while the ultrasonic sees one closer than 100 cm, it is a black-wall dropout, so trust the ultrasonic.
- Every disagreement is logged with both values, so the thresholds are tuned on recorded runs and not guessed.

#### Sensor placement and field geometry

Each position is chosen from the field dimensions in the rules: walls 100 mm high and black on the inside, pillars 50 × 50 × 100 mm, white floor mat.

| Sensor | Placement | Field geometry behind it |
|---|---|---|
| ToF × 4 | **~50 mm above the floor**, centered on the 100 mm wall height | The VL53L1X sees a 27° cone by default. Mounted low, that cone hits the white floor at ≈4× its mounting height, and a bright floor easily wins over a dark wall. Teams who mounted them low saw exactly this. With a **wide-and-short region of interest** (16 × 4 detector cells ≈ 27° × 7°), the vertical half-angle is ≈3.4°. At 80 cm the cone spans ±4.7 cm, so at 50 mm height it stays inside the 0–100 mm wall. |
| Ultrasonic L / R | Sides, perpendicular to the straight | They read the wall parallel to the current straight. The inside sensor reads the opening that triggers a corner. |
| Ultrasonic F + ToF F | Front bumper, on the centerline | They read the wall ahead. Their distance decides *when* the stop-and-turn starts, and *which* maneuver is used (forward arc vs reverse pivot). |
| ToF rear | Rear bumper | The parking lot and the reverse pivot happen backwards, where v1 had no sensor at all. |
| Camera | Front, ~20° down, wide-angle 120° | Sees both pillar columns of the straight and the corner line on the same frame. |
| BNO085 | Center, near the rotation axis | Keeps centripetal acceleration out of the fused heading. |

### 3.3 PCB & wiring

A custom two-layer PCB is the vehicle's backplane: it distributes power and carries every signal line between the ESP32, the sensors and the motor driver, so there is no breadboard or flying-wire harness to work loose. This is what let the front ultrasonic go in in under 30 minutes ([§1.1](#11-design-goals)) — the header was already there. The full editable KiCad project is in [`electrical/WRO_RevA/`](electrical/WRO_RevA/).

**Schematic** ([`schemes/schematic.png`](schemes/schematic.png)):

<p align="center">
  KiCad schematic
</p>

The ESP32 DevKit (`U1`) sits at the centre. Battery voltage (~11.1 V, 3S) comes in at the `VCC` screw terminal (`J1`) and splits two ways: the motor driver takes it directly, and a MINI560 buck (`V1`, bulk caps `C1`–`C4`) drops it to the 5 V logic rail. The RDB-14450 driver (`U2`) takes `PWM_MOTOR` / `AIN1` / `AIN2` from the ESP32 and drives `MOTOR_1/2` out to the screw terminal `J5`. The four HC-SR04s land on headers `US1`–`US4` (5 V / TRIG / ECHO / GND); their 5 V echo lines return through a BOB-12009 level shifter (`U3`) that steps `ECHO1`–`ECHO4` down to 3.3 V for the ESP32. The MPU-6050 (`U4`) is on I²C. The `TO_PI` header (`J3`) is the entire link to the Raspberry Pi — `RX` / `TX` for the V2 protocol, `READY` for the handshake, `PRGN` for the start button (`SW1`), plus 3.3 V / GND. Two status LEDs (`D1` PWR, `D2` READY) complete the operator interface from [§4.7](#47-startup-handshake).

**Populated board** ([`schemes/pcb_render.png`](schemes/pcb_render.png)):

<p align="center">
  3D render of the populated PCB
</p>

**Board outline** ([`electrical/PCB_dimensions.png`](electrical/PCB_dimensions.png)):

<p align="center">
  PCB outline and dimensions
</p>

The board is a custom non-rectangular shape (~55 mm at its widest) that nests into the chassis around the Raspberry Pi 4 and the drivetrain — the electronics-first packaging from [§1.1](#11-design-goals) in physical form. The cut-outs and the mounting-hole row let the PCB, the steering and the sensor mounts share one footprint without stacking height.

#### v2 PCB — two-floor board (in design)

The v1 board is a single layer of components shaped around the Raspberry Pi 4. The v2 chassis is ≈7 cm shorter, the Pi moves to the top, and the robot gains four ToF sensors (each with its own XSHUT line), the BNO085 UART and a second regulator. All of that does not fit on one footprint, so the v2 board is designed as **two stacked floors** on standoffs:

| Floor | Contents | Why separate |
|---|---|---|
| **Power** (bottom) | Battery input (XT60), switch and fuse, two Mini560 regulators (Pi / everything else), motor driver | Keeps the switching regulators and motor currents, with their heat and noise, away from the signal lines. It is also the heaviest floor, so it sits low. |
| **Logic** (top) | ESP32, level shifter, headers for 3 HC-SR04, 4 VL53L1X (I²C + XSHUT), BNO085 (UART), servo, start button and LEDs, the link to the Pi | All signal connectors on one accessible floor |

Status: schematic and layout in progress in KiCad. The v1 project in [`electrical/WRO_RevA/`](electrical/WRO_RevA/) remains the reference until RevB is fabricated. The wiring diagram will be updated with it.

### 3.4 Main computer — Raspberry Pi 5 (v2)

**Why we upgraded.** We profiled the Pi 4 running the real race code. The main Python thread was using **97% of one core**, and the loop ran at **14–18 fps** depending on the scene. Most of that time was spent on vision, not on the camera: ~5 ms capture, 17–22 ms color detection, 45–48 ms bird's-eye view and centerline. With the remote desktop client running, the Pi 4 also reached **84 °C** and entered thermal throttling. A faster CPU attacks every stage at once.

**Measured result.** We ran the unmodified race runtime on the Pi 5, replaying a recorded Obstacle Challenge run as the camera input at 30 fps:

| | Raspberry Pi 4 | Raspberry Pi 5 (16 GB) |
|---|---|---|
| Vision loop rate | ~15.5 fps (same run, recorded live) | **40–41.5 fps**, stable for 60 s |
| Time per frame | ~65 ms | ~25 ms |
| Temperature | up to 84 °C, throttled | 46 → 52 °C, no throttling (`0x0`) |

The Pi 5 also has the official **Active Cooler**. Its fan is controlled by the firmware: it stays off below 50 °C and speeds up in steps up to 100% at 75 °C. The **M.2 HAT+** is installed for a future NVMe SSD, which will mainly make storage more durable when recording a video of every run.

**What the port required:**
- **Per-frame constants.** Many filters and confirmations in the runtime count *frames* and were tuned at ~14 fps. At 40 fps they would run almost 3× faster in real time. The loop also doesn't wait for a new camera frame. Before racing on the Pi 5 we either cap the loop at the old rate or rescale those constants.
- **Serial port.** On the Pi 5, `/dev/serial0` points to the debug UART connector, not to the GPIO header. The ESP32 link uses `/dev/ttyAMA0` (GPIO 14/15).
- **GPIO.** The original `RPi.GPIO` library does not support the Pi 5, so we use the drop-in `rpi-lgpio` package and the code stays the same.
- **Camera.** The Pi 5 uses the smaller 22-pin camera connector, so the Camera v2 needs a 22-to-15-pin cable. The automatic camera detection did not recognize our module, so `/boot/firmware/config.txt` loads it explicitly (`camera_auto_detect=0`, `dtoverlay=imx219,cam1`). The capture pipeline must request `format=BGRx`; without it, the camera source fails to negotiate a format on the Pi 5's image processor (`not-negotiated`). BGRx comes straight from the image processor at 30 fps using ~2% CPU.
- **Live view without a monitor.** The remote-desktop client used on the Pi 4 does not work on the Pi 5 desktop (Wayland). [`pure_pursuit/cam_web.py`](src/RASPI/cam/pure_pursuit/cam_web.py) streams the camera (or the race HUD with `--hud`) to a browser, with the color-calibration controls.
- **OpenCV.** It must be the system package (`python3-opencv`), because the pip wheel is built without the GStreamer backend that the `libcamerasrc` capture pipeline needs.

---

# 4. Software Architecture

### 4.1 System overview — two controllers, one link

Responsibility is split across two processors by hardware strength:

```
        RASPBERRY PI 4 (Python, OpenCV)                          ESP32 (Arduino / C++)
 ┌───────────────────────────────────────────┐    V2     ┌────────────────────────────────────┐
 │ Camera → BEV homography → floor centerline│   UART    │ readPiSerial()  →  parse V2        │
 │ Pillar detection (HSV) + corner-line track│  ──────►  │                                    │
 │ Rolling obstacle memory (dead reckoning)  │  115200   │ 6-state FSM                        │
 │ Pure Pursuit geometric controller         │           │  SIGUIENDO / GIRANDO / RECUPERANDO │
 │ RECUPERANDO trigger (measured state)      │  ◄──────  │  CRUCERO / MANIOBRA / TERMINANDO   │
 │ builds one V2 line per processed frame    │  ACK:V2   │ cascade PID (wall + gyro)          │
 └───────────────────────────────────────────┘   ang=    │ servo + motor PWM, HC-SR04, MPU    │
                                               est= dir= └────────────────────────────────────┘
```

- The **Pi** decides *where to steer*: it turns the camera frame into a top-down view, extracts a drivable centerline, runs a Pure Pursuit controller against it, and reduces the result to a single normalized steering value plus a few status flags. It processes 1 of every 3 captured frames (~12–15 Hz effective).
- The **ESP32** decides *how to drive*: it owns the 50 Hz control loop, the finite state machine, corner detection, the recovery behaviour, and every actuator. In the Obstacle round it treats the Pi's steering value as the primary reference while Pure Pursuit is active, and falls back to its own wall + gyro PID if the Pi goes silent for more than 800 ms. In the Open round it ignores the Pi's steer altogether and runs on wall + gyro PID the whole time (§4.5).

Why not one processor? Real-time GPIO timing (ultrasonic pulses, servo/motor PWM, gyro sampling) and non-deterministic OpenCV latency don't coexist well on one core. Linux can't guarantee a µs-accurate pulse while an HSV pass is running; a microcontroller can't run OpenCV. Splitting them lets each run at its own natural rate, and a late UART packet just means the ESP32 reuses the last command instead of stalling. This trade-off is analyzed in [Section 5](#5-systemic-thinking--engineering-decisions).

**Where to start reading the code:** the Pi loop is [`pure_pursuit/runtime_nuevo.py`](src/RASPI/cam/pure_pursuit/runtime_nuevo.py) (`run()` → per-frame block); the ESP32 loop is [`PurePursuit.ino`](src/ESP32/PurePursuit/PurePursuit.ino) (`loop()` → the `switch (estado)`). Every module is annotated in [Section 8](#8-repository-structure); tunables live in [`pure_pursuit/config.py`](src/RASPI/cam/pure_pursuit/config.py).

### 4.2 Inter-controller protocol ("V2")

One line per processed frame, newline-terminated, 115200 baud. The rest of Section 4 refers to these fields by name.

**Pi → ESP32:**

```
V2,obs=+0.123,turn=0,state=pp,prio=1,mem=18,pp=1,pasado=0,intr=0
```

| Field | Meaning |
|---|---|
| `obs` | Normalized steering, `steer_deg / 60`, range −1…+1 (`+` = right). |
| `turn` | Legacy directional hint — always `0`; turn direction is resolved on the ESP32 side. |
| `state` | Human-readable label for the journal (e.g. `pp`, `avoid_red`). |
| `prio` | `1` = an obstacle is actively being avoided → **ESP32 must not start a corner turn**. |
| `mem` | Frames of obstacle memory still live → also blocks corner detection while `> 0`. |
| `pp` | `1` = Pure Pursuit steering is authoritative (suspend the wall PID). |
| `pasado` | One-frame pulse: the Pi confirms the car has *physically* cleared an obstacle → enter RECUPERANDO. |
| `intr` | Interior-pass flag (disabled by default). |

**ESP32 → Pi:**

```
ACK:V2,ang=12.34,est=S,dir=L,...debug...
```

| Field | Meaning |
|---|---|
| `ang` | Integrated IMU heading `anguloGyro` (degrees); resets to 0 at each turn. |
| `est` | FSM state — `S` SIGUIENDO, `G` GIRANDO **or** MANIOBRA, `R` RECUPERANDO, `C` CRUCERO. |
| `dir` | Track turn direction — `?` until the first turn, then `L` / `R`. |

### 4.3 Vision pipeline (Raspberry Pi — `pure_pursuit/`)

Entry point: `pure_pursuit/runtime_nuevo.py`. Per processed frame:

1. **Capture** — a threaded grabber pulls frames from the Pi camera through a libcamera/GStreamer pipeline at 640 × 480 BGR, dropping stale buffers so the loop always sees the newest frame.
2. **Bird's-eye view (`bev.py`)** — a homography (inverse-perspective mapping) warps the camera frame to a top-down 400 × 400 image at 2 mm/px. The homography comes from `bev_calib.npz`, generated once by `calibrate.py` from a **3 × 3 grid of 9 physical floor markers** (RANSAC fit). We use 9 points, not the minimum 4: a 4-point fit is exact and can't detect a mis-click or extrapolate safely beyond the marked area, while 9 points let the solver average out click noise across the full range the centerline actually uses (from just ahead of the car out to ~550 mm).
3. **Pillar detection (`vision.py`)** — HSV masks for red and green, then contour filtering by area, **solidity** (compact blob ≈ 0.7–0.9, painted line < 0.4) and **aspect ratio** (< 2.2) so the mat's coloured lines are not mistaken for pillars.
4. **Centerline (`centerline.py`)** — a floor-colour mask in the BEV, minus inflated "keep-out" disks around each obstacle. The keep-out is **asymmetric per the WRO rule**: a red pillar inflates further to its *left* (car passes on the right), a green pillar further to its *right*. Rows are sampled bottom-to-top; each row blends the free-gap center with the WRO pass-side using a weight that ramps up as the car nears the can (not a binary switch). A 1-D moving average plus a per-step Δx clamp keep the path within the servo's curvature limit.
5. **Pure Pursuit (`controller.py`)** — a geometric pure-pursuit controller in BEV pixel space. Look-ahead is **adaptive**: it shrinks from 100 px toward 78 px as the nearest can closes *longitudinally*, so the car keeps translating and arcs around the can instead of pivoting in place. Output is slew-limited to 6°/frame to kill frame-to-frame steering whip.
6. **Serialize** — the steering angle is normalized (`obs = steer_deg / 60`) and packed into one V2 line with the status flags (§4.2).

```mermaid
flowchart TB
    A["Capture — threaded grabber<br/>Pi camera 640×480 BGR, drops stale buffers"]
    B["BEV homography (bev.py)<br/>IPM warp to 400×400 top-down, 2 mm/px<br/>from bev_calib.npz (9-point RANSAC)"]
    C["Pillar detection (vision.py)<br/>HSV red/green + area + solidity + aspect ratio"]
    D["Centerline (centerline.py)<br/>floor mask minus asymmetric keep-out disks<br/>red inflates left, green inflates right<br/>pass-side weight ramps with distance"]
    E["Rolling obstacle memory (obstacle_memory.py)<br/>ego-motion: assumed speed + real IMU heading from ACK<br/>confidence decay, prune-on-pass"]
    F{"Measured RECUPERANDO trigger<br/>ARM / CLEAR / SKEW — see §4.4"}
    G["Pure Pursuit (controller.py)<br/>geometric, look-ahead 100 to 78 px adaptive<br/>slew-limited 6°/frame"]
    H["Serialize one V2 line<br/>obs = steer_deg / 60, plus prio / mem / pp / pasado"]
    A --> B
    B --> C
    B --> D
    C --> E
    E --> D
    E --> F
    D --> G
    G --> H
    F --> H
    H --> Z(["UART to ESP32 @ 115200"])
```

#### How the Pure Pursuit controller works

Pure Pursuit is a path-tracking method: instead of reacting to an *error signal*, the controller looks a fixed distance ahead along the path — the **look-ahead** — picks the point on the centerline at that distance, and computes the single steering angle whose turning arc, starting from the car's current pose, passes exactly through that point. Every frame the target point moves forward along the centerline and the car "chases" it, so the trajectory is always a smooth arc onto the path rather than a hand-tuned reaction curve.

```
          centerline (from BEV)                 look-ahead point picked at
        ·····•·····•·····•···•···•  ← target    distance  ld  along the path
                            ╲
                             ╲  arc the steering angle produces
              ┌───┐           ╲
              │car│────────────•   robot pose (rear axle = reference)
              └───┘
                 └─ α = bearing to target,  steer = atan2(2·L·sin α, ld)
```

Why it fits this problem:

- The vision pipeline already produces a **path** (the centerline), not a point to servo onto — Pure Pursuit consumes that path directly.
- The look-ahead is a single, physically meaningful tuning knob: **short = cut hard toward the path** (fast dodge), **long = ease onto it** (smooth cruise). That is exactly the behaviour the obstacle logic needs, so avoidance is folded into the *same* controller by shrinking the look-ahead near a can instead of adding a separate avoidance mode.
- It degrades gracefully: a noisy or short path just moves the target point a little; there is no integrator to wind up and no error term to spike.

```python
dx = target[0] - robot_x          # lateral offset to the look-ahead point (BEV px)
dy = robot_y - target[1]          # forward distance to it
ld = max(1.0, math.hypot(dx, dy)) # actual chord length
alpha     = math.atan2(dx, dy)                                   # bearing to the point
steer_rad = math.atan2(2.0 * C.WHEELBASE_PX * math.sin(alpha), ld)  # pure-pursuit arc
steer_deg = math.degrees(steer_rad)

if bev_obstacles:                                   # a can is in play
    steer_deg *= self._distance_steer_gain(...)     # ramp 0.30→1.0 as it closes
steer_deg = max(-C.MAX_STEER_DEG, min(C.MAX_STEER_DEG, steer_deg))
steer_deg = clamp(steer_deg, prev ± C.PP_STEER_SLEW_DEG)   # 6°/frame slew limit
```

`adaptive_lookahead` shrinks the look-ahead from 100 px toward 78 px, and `_distance_steer_gain` ramps the steering scale from 0.30 up to 1.0, both as the nearest can closes. Both key off the **longitudinal** distance to the can (forward gap), not the Euclidean one: a can still off to the side but level with the car used to keep those values relaxed, and the car drove straight past the point where it should have started turning. The WRO pass-side bias (right of red, left of green) is *not* handled here — it is already baked into the centerline by `centerline.py`, so the controller only has to follow the path it is given.

If `bev_calib.npz` is missing, the runtime falls back to a simple reactive PID on the pillar's x-position in the raw frame (`RED_TARGET_PX` / `GREEN_TARGET_PX`) so the car is never left without a controller.

### 4.4 Obstacle handling (Obstacle Challenge)

**Rolling obstacle memory (`obstacle_memory.py`).** The BEV only contains what the camera sees *now*; as the car closes on a can, the can leaves the bottom of the frame, its keep-out disc vanishes, and the centerline snaps back to center — cutting the corner onto the can. The memory fixes this: seen cans are stored as `(x, y, colour, confidence)` in robot-relative BEV coordinates and, every frame, the ego-motion is applied to every remembered can — forward travel from an assumed speed, rotation from the **real IMU heading change** in the ESP32 acknowledgement:

```python
dheading = heading_deg - self._prev_heading          # real Δ from the ACK, degrees
ds_px    = (C.ROBOT_SPEED_MMS * dt_s) / C.MM_PER_PX  # assumed forward advance, BEV px
# a hard dodge rotates the car without translating it — shrink ds_px when |dheading| is large
ds_px   *= turn_brake(dheading)
self._advance(ds_px, dheading)     # each can: y += ds_px, then rotate −dheading about the robot
```

Fresh detections are merged in, unseen cans decay in confidence and are pruned once genuinely passed. The inflated keep-out therefore persists until the car has physically cleared the can. The `heading_deg` this relies on is exactly the value the ESP32 integrates for its own control (see §4.6) and echoes back — one shared heading, so the map rotates by the same angle the car actually turned.

**"Mine" vs "beyond the corner" (`corner_lines.py`).** The mat's orange corner lines are tracked row-by-row in the BEV. Each remembered can is classified as *mine* (on my straight, must be avoided) or *beyond* (on the next straight, ignore for now), with asymmetric hysteresis — quick to start avoiding, slow to stop — because starting to dodge is the safe side of a wrong call.

**Far hint (`far_hint.py`).** A PD controller on a pillar's offset in the *raw* camera frame (before it projects into the BEV range) nudges the steering to pre-center on a distant can, capped at ±12° so it can only hint, never dodge.

**Mid-turn detector (`mid_turn.py`).** While the ESP32 is turning, the rolling memory is disabled (its motion model assumes forward travel, which a pivot violates). This detector instead uses only the raw per-frame BEV projections and requires a same-colour can in a consistent position across several frames inside a close forward cone to "confirm" it. **Phase 1 (current): observe and log only** — it writes `[MTURN]` lines to the journal and does not yet change steering, so we can measure its reliability on-track before wiring it into the firmware.

#### Triggering RECUPERANDO from the obstacle memory

**The problem.** When the car has to swing wide around a can with no room to spare, it finishes the pass **crooked** — pointing 30–60° off the straight — and often with one wall out of ultrasonic range. At that exact moment the camera view is the least trustworthy (the centerline is short and skewed), so letting Pure Pursuit "straighten itself" from what it sees tends to over- or under-correct into a wall. The fix is to hand the wheel to the ESP32's wall + gyro PID (state `RECUPERANDO`) until the chassis is realigned — but *only* for a hard dodge. A gentle dodge with space to spare straightens itself fine and should not stop for a recovery.

**The trigger** (`_measured_recup_trigger` in [`runtime_nuevo.py`](src/RASPI/cam/pure_pursuit/runtime_nuevo.py)) does not dead-reckon the can itself — it reads the state the obstacle memory and the IMU already provide, and needs three things to line up:

```
1. ARM   a real dodge is in progress:
         the centerline's avoidance weight near the car's axis has been
         ≥ RECUP_MEAS_ARM_W for RECUP_MEAS_ARM_FRAMES straight frames.
         On arming, snapshot heading_ref = current heading (the straight's heading).

2. CLEAR the memory no longer places any Red/Green can both far enough ahead
         of the axis AND close enough to the side to be in the way
         (going straight, the car's edge would clear it) — held for
         RECUP_MEAS_CLEAR_FRAMES frames (or just 1 if a corner is imminent).

3. SKEW  |heading − heading_ref| ≥ RECUP_MEAS_HEADING_DEG   (25°)
         → there is actually something to straighten.

ARM && CLEAR && SKEW  →  emit pasado=1  (one-frame pulse)  →  ESP32 enters RECUPERANDO
CLEAR but never SKEW for RECUP_MEAS_GENTLE_FRAMES  →  disarm quietly, no RECUPERANDO
```

```mermaid
flowchart TB
    S(["Each processed frame"]) --> ARM{"Centerline avoidance weight near the car axis<br/>>= ARM_W for ARM_FRAMES consecutive frames?"}
    ARM -- no --> S
    ARM -- yes --> SNAP["Snapshot heading_ref = current heading<br/>(the straight's heading)"]
    SNAP --> CLR{"Memory places NO red/green can both far enough ahead<br/>of the axis AND close enough to the side to be in the way?<br/>held CLEAR_FRAMES frames (or 1 if a corner is imminent)"}
    CLR -- no --> HOLD["Keep dodging (pasado = 0)"]
    HOLD --> CLR
    CLR -- yes --> SKEW{"abs(heading − heading_ref) >= 25° ?"}
    SKEW -- "yes" --> FIRE["Emit pasado = 1 (one-frame pulse)<br/>trigger disarms — fires once per dodge"]
    SKEW -- "no, for GENTLE_FRAMES" --> DIS["Disarm quietly — the gentle dodge<br/>straightens itself, no RECUPERANDO"]
    FIRE --> ESP(["ESP32: SIGUIENDO → RECUPERANDO<br/>wall + gyro PID realigns the chassis"])
```

Condition 3 is what separates the two cases: same "can is now behind me" geometry, but only the crooked one triggers a recovery. The trigger disarms on fire, so it emits **once per dodge** — a can that lingers in memory while the ESP32 straightens can't re-fire it. The can positions it checks are the same `(x, y)` the memory maintains — corrected by fresh detections while the can is visible, and carried by the *same* ego-motion the centerline uses once it isn't (see the memory snippet above) — so the trigger and the path always agree on where the can is.

This replaced an earlier approach that anchored the can's position when first seen and dead-reckoned it forward with an *assumed* speed and a bicycle model; that anchor drifted 200–400 mm within 1–2 s and fired either early (nose into the can) or far too late.

### 4.5 ESP32 finite state machine (`src/ESP32/PurePursuit/PurePursuit.ino`)

```
enum Estado { SIGUIENDO, RECUPERANDO, GIRANDO, CRUCERO, MANIOBRA, TERMINANDO, INICIO, ESTACIONANDO, ESTACIONANDO_PUNTA };
```

```mermaid
stateDiagram-v2
    [*] --> WAIT_PI: setup() blocks on READY
    WAIT_PI --> WAIT_FIRST_V2: READY acknowledged
    WAIT_FIRST_V2 --> SIGUIENDO: first V2 line (motor gated at 0 until here)

    SIGUIENDO --> RECUPERANDO: pasado=1, obstacle physically cleared [Obstacle]
    SIGUIENDO --> GIRANDO: corner detected, cooldown elapsed [Open]
    SIGUIENDO --> CRUCERO: straight clean, front sensor < FRONT_CRUCERO_CM [Obstacle]

    RECUPERANDO --> SIGUIENDO: heading settled or timeout, lane clear
    RECUPERANDO --> CRUCERO: heading settled or timeout, wall ahead [Obstacle]

    GIRANDO --> SIGUIENDO: reaches AngGiro, turn counted, heading re-zeroed
    GIRANDO --> TERMINANDO: 12th turn

    CRUCERO --> SIGUIENDO: a new "mine" obstacle appears, not yet committed
    CRUCERO --> MANIOBRA: front sensor at turn threshold (debounced), or CRUCERO timeout

    MANIOBRA --> SIGUIENDO: sub-sequence done, turn counted, new straight from 0
    MANIOBRA --> TERMINANDO: 12th turn

    TERMINANDO --> [*]: drive like SIGUIENDO for TERMINANDO_MS, then stop

    note right of MANIOBRA
      Phase machine (a motor-coast precedes every reversal — H-bridge safety):
      0 coast, 1 pivot (forward arc or reverse) to EXIT_DEG,
      2 coast, 4 straight back-off, 5 coast, then finish.
      Phase 3 = reverse stalled, coast, restart the pivot forward.
    end note
```

*This is the complete state machine as it stands on branch `SectionTurning` — the current firmware. One flag, `const bool rondaObstaculos`, selects the profile. `false` (Open Challenge): only `SIGUIENDO` / `GIRANDO` / `RECUPERANDO` / `TERMINANDO` are reachable and corners are the continuous `GIRANDO` arc. `true` (Obstacle Challenge): `GIRANDO` is replaced by the segmented `CRUCERO` → `MANIOBRA` sequence and the `pasado`-driven `RECUPERANDO` is enabled. `RECUPERANDO` never aborts on a new obstacle — it straightens the chassis first, then hands back to `SIGUIENDO`, or to `CRUCERO` if the corner is already in reach. The `main` branch still carries an earlier 3-state cut (`SIGUIENDO` / `RECUPERANDO` / `GIRANDO`); the `SectionTurning` merge is tracked as iteration log v3.0. `WAIT_PI` / `WAIT_FIRST_V2` are the startup handshake (§4.7).*

| State | Role |
|---|---|
| **SIGUIENDO** | Normal driving. In the **Obstacle round**, steering = Pi's Pure Pursuit value, blended with a light gyro correction (weight 0.12) and, only on a clean straight, the wall PID (weight 0.30). In the **Open round** the Pi's steer is ignored entirely — steering is pure wall PID + gyro PID (see §4.5.1). Watches for the next corner and for obstacle flags from the Pi. |
| **GIRANDO** | Continuous corner (**Open round only**). Servo held at full lock, motor speed ramped down in steps as `\|anguloGyro\|` grows, exits at `\|anguloGyro\| ≥ AngGiro` — **76°** in the Open round (the continuous turn coasts the rest on inertia) vs. 90° for the Obstacle round. The first corner latches the track's turn direction from whichever wall opened up. 12 corners = 3 laps → `TERMINANDO`. |
| **RECUPERANDO** | *(Obstacle round)* Entered on the Pi's `pasado=1` pulse. Vision is handed off; wall PID + gyro PID (with widened limits) straighten the chassis back into the lane. Exits when the heading error settles (with a timeout safety net for corners where one wall legitimately reads "open"). |
| **CRUCERO** | *(Obstacle round)* Straight is clean and a corner is near (front sensor < 80 cm). The car drives straight on heading toward the wall: far away, vision keeps the centerline straight; once inside `CRUCERO_GYRO_CM`, control is pure gyro + wall PID. A new obstacle sends it back to SIGUIENDO. |
| **MANIOBRA** | *(Obstacle round)* Replaces the continuous turn. At 30–60 cm from the wall a one-time decision is latched: **turn direction** = the side whose wall is open; **forward arc vs. reverse pivot** = chosen from the distance to the *outer* wall of the turn (tight against it → reverse pivot; room to swing → forward arc). A multi-phase sub-machine runs it, with motor-**coast** phases inserted between every direction reversal (plugging the H-bridge under load destroyed a TB6612 during testing). An optional short straight back-off afterward buys room on the new straight. Then it straightens, zeroes the heading for the new straight, counts the turn and returns to SIGUIENDO. |
| **TERMINANDO** | Entered automatically after the 12th turn **instead of braking on the spot**. Drives exactly like SIGUIENDO (same controller, but corner detection disabled) for `TERMINANDO_MS` (~1 s, tunable) so the car rolls forward into the start area, then cuts the motor and ends the race. Keeps the finish inside the start section instead of wherever the last corner happened to end. |

The turn-direction is latched once (all corners of a WRO track turn the same way); the forward-vs-reverse choice is made fresh at every corner from the distance to the **outer** wall of the turn ([`decidirManiobra()`](src/ESP32/PurePursuit/PurePursuit.ino)):

```cpp
// outer wall = the one that is NOT the opening (right turn → left wall, and vice-versa)
long distExt = maniobraGirarDer ? distL : distR;
maniobraReversa   = (distExt >= HUG_CM);                    // room to swing → reverse pivot
maniobraRetroceso = (distExt >  MANIOBRA_BACKOFF_MIN_CM);   // slack → short back-off after
```

**One flag switches the whole driving profile:** `const bool rondaObstaculos` at the top of `PurePursuit.ino`.

| | Open Challenge (`false`) | Obstacle Challenge (`true`) |
|---|---|---|
| Steering source | ESP32 wall PID + gyro PID **only** — the Pi's Pure Pursuit steer, `prio`/`mem`/`pasado` flags are all ignored | Pi Pure Pursuit centerline; PID as blend / fallback / RECUPERANDO |
| Corner turn | continuous `GIRANDO` | `CRUCERO` → `MANIOBRA` segmented |
| Turn target `AngGiro` | 76° (the continuous turn coasts the rest on inertia) | 90° |
| Motor PWM ceiling `MOTOR_MAX` | 180 — fast; the in-turn speed ramp does the slowing | 100 — slow, for fine maneuvers |
| `RECUPERANDO` / obstacle handling | never entered | active |

`TERMINANDO` and the cascade PID run in both.

#### 4.5.1 Open-round corner hardening

With the Pi's vision out of the loop, three guards keep the continuous turn honest:

- **`giroArmado` — corridor arm.** `detectarEsquina()` is not allowed to fire a turn until the car has first confirmed it is *inside* a corridor: both side walls < 100 cm for `PASILLO_FRAMES` (3) consecutive frames. A wide reading in the start zone therefore can't trigger a false first turn. Once armed it stays armed for the whole run, so real corners are never delayed by it (unlike a fixed time lockout).
- **Front-wall approach slow-down.** When the front sensor sees the end wall closer than `FRONT_SLOWDOWN_CM` (60 cm), speed drops to `VEL_APROX_CERRADA` (140) so `detectarEsquina()` gets a clean read of which side opens before the car is on top of the corner.
- **`marchaIniciada` timer re-anchor.** The start-guard timer (`timeStart`) is reset to the instant the car actually starts rolling — not to when `READY` arrived seconds earlier — so its window is measured from roll-off.

#### 4.5.2 States added for the national final: start from the lot and parking

The diagram above shows the six driving states. Three more were added between 2026-09-07 and the national final:

| State | Entered when | What it does |
|---|---|---|
| `INICIO` | The Pi sends `inicio=1` (the car starts inside the parking lot) | Scripted S-shaped exit from the lot, gyro-checked, then `SIGUIENDO` |
| `ESTACIONANDO` | Last corner, parking mode `PARK_PARALELO` | Parallel parking in reverse inside the magenta lot |
| `ESTACIONANDO_PUNTA` | Last corner, parking mode `PARK_PUNTA` | Simpler nose-in partial parking (fallback) |

- **Start in the lot.** While disarmed, the Pi measures the share of magenta in the frame. When the button is pressed it decides once whether the car is inside the parking lot, and sends `inicio=1` if so. The ESP32 then runs `INICIO`: it swings out of the lot, drives straight, counter-steers back to the track heading, and backs up briefly to square up before the first straight.
- **Parking.** After the last corner the car follows the outer wall. It detects the lot from the side ultrasonic profile (wall → gap → wall), and the camera confirms the magenta walls. Then it parks **in reverse** in `ESTACIONANDO`. During parking, the heading reference is re-measured against the wall to cancel the gyro drift collected over 3 laps (`PARK_TRIM_*`). Runs 1025, 1052 and 1064 produced perfect parallel parks, and we keep their constants as the reference set.

### 4.6 Cascade PID (always running underneath)

Even in Pure Pursuit mode the ESP32 computes its dual cascade PID every loop — it is the fallback, the RECUPERANDO/CRUCERO controller, and the blend term in SIGUIENDO.

```
                ┌────────────────────┐   heading    ┌────────────────────┐
  distL─distR ─►│     OUTER PID      │─ setpoint ──►│     INNER PID      │──► servo
                │   (wall centering) │              │  (heading control) │
                └────────────────────┘              └────────────────────┘
                         ▲                                    ▲
                  HC-SR04 readings                    MPU-6050 heading
```

The single-loop `error = distL − distR` controller it replaced failed past ~30° of yaw: the HC-SR04's conical beam hits the wall obliquely, both sensors over-report, the difference sits near zero while the car drifts into a wall. The outer loop turns lateral wall error into a target heading; the inner loop drives the servo to that heading using the IMU, which doesn't care about beam geometry.

**Tuned gains:** `KpWall 1.0 / KiWall 0.0 / KdWall 1.2`, `KpGyro 2.0 / KiGyro 0.0 / KdGyro 0.5`. Both integral terms are **disabled on purpose** — integral built up on long straights and released as a large steering impulse at corner entry, overshooting into the opposite wall. The derivative terms give enough steady-state correction on their own. Raw ultrasonic reads pass through an EMA filter (`alpha = 0.85`) before the PID.

```cpp
// OUTER: lateral wall error → steering contribution (Ki = 0)
errorWall  = constrain(distL - distR, -50, 50);
outputWall = KpWall*errorWall + KdWall*(errorWall - prevErrorWall)/dt;

// INNER: heading error vs. the straight's reference heading (Ki = 0)
errorGyro  = anguloObjetivo - anguloGyro;
outputGyro = KpGyro*errorGyro + KdGyro*(errorGyro - prevErrorGyro)/dt;

// SIGUIENDO with Pure Pursuit active: the Pi's steer leads, PID only trims a clean straight
servo = centroServo - (steerDeg - outputGyro*PP_GYRO_BLEND - outputWall*PP_WALL_BLEND);
// fallback / RECUPERANDO / CRUCERO-near-wall: PID alone
// servo = centroServo + (outputWall + outputGyro);
```

Heading is integrated on the ESP32 from the gyro Z axis, with the 1°/s deadband that keeps MEMS thermal noise from drifting the straight-line heading:

```cpp
float gz = mpu.getGyroZ() / gyroScale;
if (abs(gz) < 1.0) gz = 0;        // 1°/s deadband
anguloGyro += gz * dt;            // this is the value echoed back to the Pi
```

### 4.7 Startup handshake

1. Pi lights the LED on **GPIO 27** — "Pi is up".
2. Pi waits for the start button on **GPIO 17**.
3. Camera warm-up (~40 frames discarded to settle exposure).
4. Pi sends `READY` ×3; the ESP32 has been blocking in `setup()` waiting for it.
5. ESP32 replies `ACK:READY`, then **holds the motor at zero until the first real V2 line arrives** (a gate so the car never rolls forward on the fallback PID before Pure Pursuit is actually streaming). On the first frame it then rolls, `marchaIniciada` re-anchors the start-guard timer to that instant.
6. Main loop runs until 12 turns are counted, then `TERMINANDO` drives ~1 s more into the start area and stops.

```mermaid
sequenceDiagram
    participant Pi as Raspberry Pi
    participant ESP as ESP32
    Pi->>Pi: Light LED on GPIO 27 ("Pi is up")
    Pi->>Pi: Wait for start button (GPIO 17)
    Pi->>Pi: Camera warm-up (~40 frames discarded)
    Note over ESP: setup() is blocking, waiting for READY
    Pi->>ESP: READY x3
    ESP->>Pi: ACK:READY
    Note over ESP: Motor held at 0 until the first V2 line
    Pi->>ESP: First V2 line (obs + flags)
    Note over ESP: Car rolls — start-guard timer re-anchored to this instant
    loop Every processed frame (~12-15 Hz)
        Pi->>ESP: V2 line — obs, prio, mem, pp, pasado
        ESP->>Pi: ACK:V2 — ang (heading), est (S/G/R), dir (?/L/R)
    end
    Note over ESP: 12 turns counted, then roll ~1 s into start zone and stop
```

### 4.8 Development status

| Module | Challenge | Status |
|---|---|---|
| BEV homography + 9-point calibration tool | both | Complete |
| Floor centerline extraction | both | Complete |
| Pure Pursuit geometric controller | both | Complete, track-tuned |
| ESP32 cascade PID + fallback | both | Complete |
| Continuous corner turn (GIRANDO) | Open | Complete, track-tuned |
| Open-round pure-PID mode + corner hardening (`giroArmado`, approach slow-down) | Open | Implemented, not track-tuned |
| Return-to-start finish (TERMINANDO) | both | Implemented, not track-tuned |
| Pillar detection (HSV + shape filter) | Obstacle | Complete |
| Asymmetric WRO keep-out in centerline | Obstacle | Complete |
| Rolling obstacle memory (dead reckoning) | Obstacle | Complete, track-tuned |
| Corner-line "mine / beyond" classifier | Obstacle | Complete |
| Measured-state RECUPERANDO trigger | Obstacle | Complete, track-tuned |
| Segmented turn (CRUCERO → MANIOBRA) | Obstacle | Raced at the national final; forward/reverse hysteresis added after it ([ERR-22](docs/engineering-log.md#err-22--the-corner-maneuver-changed-its-mind-at-the-last-moment)) |
| Mid-turn cone detector | Obstacle | Phase 1 — logging only |
| Start from the parking lot (`INICIO`) | Obstacle | Raced at the national final |
| Parallel parking (`ESTACIONANDO`) | Obstacle | Working in testing — perfect parks in runs 1025, 1052, 1064 |
| Floor-referenced color correction + ratio tests | both | Complete ([ERR-15](docs/engineering-log.md#err-15--in-a-darker-room-the-orange-line-was-read-as-red), [ERR-17](docs/engineering-log.md#err-17--strong-light-tape-read-as-red-pale-floor-read-as-green)) |
| Raspberry Pi 5 port | both | In progress — pipeline at 40 fps on recorded video; per-frame constants pending (§3.4) |
| VL53L1X ToF sensors | both | Bench testing (§3.2) |

---

# 5. Systemic Thinking & Engineering Decisions

### 5.0 Design constraints

Every decision in this section was made inside these limits:

| Constraint | Source | Limit | How it shaped the robot |
|---|---|---|---|
| Size | Rule 11.1 | ≤ 300 × 200 × 300 mm | We stay far below it on purpose (v2 ≈17 cm long) to have room to dodge and park ([§2.6](#26-v2-chassis--shorter-car-pi-on-top)) |
| Weight | Rule 11.2 | ≤ 1.5 kg | 564 g in v1; light enough that the N20 at 100:1 accelerates cleanly |
| Drive | Rule 11.3 | One driving axle and one steering actuator; no differential drive | Ackermann rack-and-pinion + a printed rear differential |
| No radio during rounds | Rule 11.10 | Wi-Fi, Bluetooth and Tailscale must be off | All debugging is offline: a recorded video and journal per run. The live view is used only in practice |
| No manual calibration at the start | Rule 9.9 | Nothing set by hand on the table | Gyro bias measured automatically at boot; camera and color calibration done in the practice time |
| Black walls | Field rules 13.3–13.4 | Dark, IR-absorbing walls | Ultrasonic + ToF cross-check ([§3.2](#why-both-ultrasonic-and-tof)) |
| Round time and ranking | Rules 9.1, 10.7–10.8 | 3 minutes; points first, time breaks ties | Points over time: stop-and-turn corners ([§4.5](#45-esp32-finite-state-machine-srcesp32purepursuitpurepursuitino)) |
| Processing | Raspberry Pi 4 | 14–18 fps, compute-bound (97% of one core) | Raspberry Pi 5: 40 fps on the same pipeline ([§3.4](#34-main-computer--raspberry-pi-5-v2)) |
| Heat | Enclosed Pi 4 | 84 °C → thermal throttling | Pi 5 + Active Cooler, mounted on top ([§2.6](#26-v2-chassis--shorter-car-pi-on-top)) |
| Power quality | Pi undervoltage | A 0.3 V drop throttled the CPU | 22 AWG wiring; a dedicated regulator for the Pi in v2 ([§3.1](#v2-power-budget)) |
| Battery voltage | Open-loop motor (v1) | Behavior changes with charge level | Race window of 11.70–12.15 V; v2 encoder motor mounted for closed-loop speed |
| Time | Calendar | ~11 weeks between the national (09-19) and international (12-08) finals; documentation due 11-24 | Every change must be checkable on recorded runs (replay) before it gets track time |
| Budget | Team | v1 ≈155 USD; the Raspberry Pi 5 alone is ≈410 USD | The Pi 5 is the big v2 expense; the sensors were picked from the low-cost, widely documented ones (VL53L1X, BNO085) |

### 5.1 Subsystem interaction map

```mermaid
flowchart LR
    subgraph PI["Raspberry Pi 4 — vision and planning"]
        CAM["Pi camera"] --> BEV["BEV homography"]
        BEV --> PD["Pillar detection (HSV)"]
        BEV --> CL["Centerline<br/>asymmetric keep-out"]
        PD --> OM["Rolling obstacle memory"]
        OM --> CL
        OM --> TRG["RECUPERANDO trigger"]
        CL --> PP["Pure Pursuit"]
    end
    subgraph ESP["ESP32 — real-time control"]
        OUT["OUTER PID<br/>wall centering"] --> INN["INNER PID<br/>heading via IMU"]
        FSM["Finite state machine"]
        SEG["CRUCERO / MANIOBRA<br/>segmented turn"]
        INN --> ACT(["servo + motor PWM"])
        FSM --> ACT
        SEG --> ACT
    end
    USLR["HC-SR04 left / right"] --> OUT
    USF["HC-SR04 front"] --> SEG
    IMU["MPU-6050"] --> INN
    PP -- "obs (V2 @ 115200)" --> FSM
    TRG -- "prio / mem / pasado" --> FSM
    IMU -- "ACK: heading" --> OM
```

The IMU heading is the shared currency: the ESP32 integrates it for its own control *and* ships it back so the Pi's obstacle memory can rotate its map by the exact same angle. Everything the Pi decides reaches the ESP32 as four flags and one number; everything the ESP32 knows about its own state reaches the Pi as three fields. Neither side can stall the other.

### 5.2 Key engineering trade-offs

**Trade-off 1 — one processor vs. two.** One ESP32 would remove the UART protocol, the Linux boot time and the sync logic. But real-time computer vision breaks single-core timing: a 640 × 480 HSV pass is 8–15 ms on the Pi 4, and running it alongside µs-accurate GPIO pulses gives non-deterministic jitter. Splitting by hardware strength (Pi = vision + planning, ESP32 = timing + actuation) lets each run at its own rate; a delayed packet just means the ESP32 reuses the last command. The cost — a protocol to maintain and two codebases — was worth deterministic control.

**Trade-off 2 — VL53L0X ToF vs. HC-SR04 ultrasonic.** ToF wins on paper (±3 mm vs ±15 mm, narrow beam). But the WRO field's matte-black walls absorbed the 940 nm IR and returned out-of-range at 300 mm in our tests. Ultrasonic reflects off anything. We chose reliability and closed the accuracy gap with EMA filtering, a front-channel median filter, and the cascade PID.

**Trade-off 3 — reactive steering vs. geometric Pure Pursuit.** The first vision controller steered proportionally to the pillar's pixel offset. It over-reacted close in and under-reacted far out, and had no model of the car's path. Pure Pursuit against a BEV centerline gives a geometrically correct steering angle for a chosen look-ahead, and the look-ahead becomes a single tuning knob for "how hard to dodge". The cost is the BEV calibration step; the payoff is predictable arcs instead of hand-tuned reaction curves.

**Trade-off 4 — forgetting a can when it leaves the frame vs. a rolling memory.** The honest, stateless option is to only avoid what the camera sees now — but that cuts the corner onto a can the moment it drops out of view. The rolling memory keeps the keep-out alive using dead reckoning (assumed speed + real IMU rotation). The risk it adds — a "ghost" can from accumulated error — is bounded by confidence decay and a prune-on-pass rule, and is the safer failure (dodge a can that's already gone vs. clip one that's still there).

**Trade-off 5 — continuous turn vs. segmented stop-and-maneuver (Obstacle round).** A continuous 90° arc is fast and simple and works well in the Open round. In the Obstacle round, a can placed near the corner mouth turns that blind arc into a coin-flip. The `SectionTurning` design trades speed for certainty: cruise straight to a known distance from the wall (front sensor), stop, then run a deterministic maneuver — a forward arc if there's room, a reverse pivot if the car is tight against the outer wall. It is slower, but every corner becomes repeatable, which is the same principle that drove the 100:1 gear choice.

**Trade-off 6 — forward arc vs. reverse pivot inside MANIOBRA.** A forward arc needs clear space ahead to swing through; a reverse pivot needs the car close to the wall first. Rather than pick one, the firmware measures the distance to the outer wall of the turn and chooses per corner, with a reverse-timeout that bails out into a forward finish if the pivot stalls.

### 5.3 Iteration log

Structural changes and the tuning passes that revealed something — routine per-run parameter tuning in `config.py` between track sessions is not listed. Each row links to the commit that introduced the change. `Status`: **Shipped** (on `main`, track-validated) · **On branch** (implemented, still tuning) · **Superseded** (replaced by a later row) · **Reverted** (tried on track, backed out).

A dated, phase-by-phase account of the same history — including the pre-repo design and per-peripheral bring-up work — is in the [Engineering Journal](ENGINEERING_JOURNAL.md).

| Stage | Date | Change | Why it changed | Evidence | Status |
|---|---|---|---|---|---|
| Mechanical + PCB | 2026-04-13 → 04-24 | Chassis, rack-and-pinion steering, printed differential and power PCB, designed from scratch | New vehicle every season | `283078e` … `51ea239` | Shipped |
| First firmware | 2026-05-09 | Single-loop PID on `distL − distR`, VL53L0X ToF ×2, 3-state FSM (`Controller_PI.ino`) | First open-round lap | `61544cb` | Superseded |
| v1.1 — ToF → ultrasonic | 2026-05 | Both VL53L0X replaced with HC-SR04 | ToF lost the black wall past ~70 cm — [ERR-01](#err-01--vl53l0x-lost-the-black-wall-past-70-cm) | `61544cb` era | Shipped |
| v1.2 — remove the integrators | 2026-05 → 06 | `Ki = 0` on both PID loops | Integral wound up on the straights and released as one impulse at corner entry → overshoot into the far wall | `Controller_PI.ino` history | Shipped |
| v1.3 — cascade PID | 2026-05 → 06 | Outer loop (wall error → target heading) + inner loop (heading → servo, via IMU) | The `distL − distR` error goes blind past ~30° of yaw — [ERR-02](#err-02--wall-error-goes-blind-at-high-yaw) | `Controller_PI.ino` history | Shipped |
| Camera integration | 2026-05-23 | Pi camera, track-edge detection, BEV calibration tool (`calibrate.py`) | Lane geometry the ultrasonics can't see | `21fe8df`, `5797487` | Superseded |
| Two-controller split + deploy infra | 2026-06-08 → 06-09 | Pi ↔ ESP32 over UART; `wro-runtime.service`, VNC, push-to-deploy CI | OpenCV latency and µs GPIO timing can't share one core ([§5.2](#52-key-engineering-trade-offs)) | `69f82a9`, `a065d78` | Shipped |
| v2.0 — Pure Pursuit + centerline | 2026-06-13 → 06-22 | BEV homography → floor centerline → geometric Pure Pursuit (`pure_pursuit/`) | Reactive pillar-offset PID had no path model — over-reacted near, under-reacted far | `95f3744`, `e494d8c`, `556266b` | Shipped |
| Camera lens FOV 63° → 120° | 2026-07 → 08-07 | Wide-angle NoIR lens (swapped over the July break); on return, pinned white-balance (`awb-enable=false colour-gains=<1.2,1.5>`) and re-tuned the obstacle RGB ranges | Needed more forward range for the obstacle round; the wide lens has no IR-cut filter, so the raw image had a heavy red cast — [ERR-03](#err-03--wide-angle-noir-lens-put-a-red-cast-on-every-frame) | `945c2f1` | Shipped |
| v2.1 — offline sim | 2026-08-11 | Kinematic bicycle sim (`pure_pursuit_sim.py`, 520 lines) + `runtime_nuevo.py` | Tune controller logic without track time | `0a2c5d2` | Shipped |
| v2.2 — BEV calibration 4 → 9 points | 2026-08-13 | RANSAC fit over a 3×3 marker grid | A 4-point fit is exact — no way to reject a mis-click or check reprojection error | `daf1e03` | Shipped |
| v2.3 — corner-line detection | 2026-08-17 → 08-19 | Orange / blue ground-line tracking in the BEV | Turn trigger + a "my straight vs. the next one" boundary for obstacles | `d3a611e`, `8edc1b8` | Shipped |
| v2.4 — wall-aware steering (`ParedCenterline`) | 2026-08-20 → 08-21 | Centerline biased by ultrasonic wall distance; V2 protocol fixes | Centerline alone drifted toward the outer wall on wide corners | merges `f5066e1`, `24b2ec7` | Shipped |
| Open round validated | 2026-08-28 | — | 10 complete autonomous runs from varied start positions and field configs → focus moved to the Obstacle Challenge | [§6.2](#62-results-to-date) | Shipped |
| v2.5 — rolling obstacle memory | 2026-08-24 → 08-27 | Seen cans kept in a robot-relative map, advanced by assumed speed + **real IMU heading** from the ACK | Can leaves the frame → keep-out vanishes → centerline cuts the corner onto it | `a41ac0e`, `3c96abf`, `57d3218` | Shipped |
| v2.6 — hot start + run recording | 2026-08-28 | Pipeline runs disarmed during the button delay; ESP32 gated on the first V2 line; MJPG `.avi` HUD capture from button-press | Cold camera/serial cost ~2 s at the start; every run now leaves a reviewable artifact | `3245c1c`, `2355caf`, `f257371` | Shipped |
| v2.7 — undervoltage fix → frame-rate rescale | 2026-08-28 | Re-fed the Pi through 22 AWG leads (was dropping 0.3 V PCB→Pi → brown-outs, garbled frames); loop went ~7 → ~14 Hz; re-scaled every per-frame knob (slew, recovery frames, look-ahead floor) | Half the tunables were calibrated at 7 Hz and were now firing twice as fast — [ERR-08](#err-08--raspberry-pi-undervoltage-from-undersized-power-wiring) | `e4ca4f9`, `1a19cdb` | Shipped |
| v2.8 — pivot-trap root cause | 2026-08-28 → 08-29 | `LOOKAHEAD_MIN_PX` 60 → 78 (60 saturated the PP geometry); adaptive look-ahead + steer-gain re-keyed on the **longitudinal** gap; `forget_color_obstacles()` on pass so the centerline un-bends | Near a can the steer term hit ±0.9 (≈ full lock) → the car pivoted in place instead of arcing; `y` never advanced, RECUPERANDO never armed — [ERR-06](#err-06--the-car-pivoted-in-place-instead-of-arcing) | `1daf563` | Shipped |
| v2.9 — RECUPERANDO: anchor → measured state | 2026-08-28 → 08-29 | Retired the geometric dead-reckoning anchor; the trigger now reads the centerline avoidance weight, a heading snapshot, and the memory's own "is a can still in the way" test (`ARM` / `CLEAR` / `SKEW`) | The anchor integrated an *assumed* linear speed and drifted 200–400 mm in 1–2 s whenever the car had to turn hard — [ERR-07](#err-07--recuperando-trigger-tied-to-assumed-linear-speed) | `f24c547` → `25d0565` → **`52549c8`** | Shipped |
| v2.10 — turn-direction from the orange line | 2026-08-31 | Direction latched from the orange corner-line slope **during the run**, not pre-set | A pre-set direction is one more thing to get wrong at check-in | `a72a751`, `e641817` | Shipped |
| v2.11 — exterior cone at the corner mouth | 2026-08-31 | A can right at the corner: drive straight past it, *then* turn | The blind turn arc would sweep into it | `4e5ca40` | Shipped |
| v2.12 — camera-safe service restart | 2026-08-31 | CI + ops use `stop → sleep 4 → start`, never `systemctl restart` | `restart` doesn't release the CSI device — camera wedges, LED stays dark | `9aff6c9` | Shipped |
| v3.0 — segmented turns (`SectionTurning`) | 2026-09-01 | Obstacle round only: `GIRANDO` → `CRUCERO` (cruise to a set distance on the front sensor) → `MANIOBRA` (forward arc **or** reverse pivot from outer-wall distance); motor-coast phase before every direction reversal | A can at the corner mouth makes a blind 90° arc a coin-flip; a missing coast delay had already killed a driver + a motor — [ERR-04](#err-04--tb6612-and-motor-destroyed-by-a-reversal-with-no-coast-delay) | `9219f17` (+386 lines to `.ino`) | On branch |
| v3.1 — mid-turn cone detector | 2026-08-31 | `mid_turn.py` — raw per-frame BEV projections (rolling memory is off during a pivot); **Phase 1: log only** | A can first seen *during* the turn ends up beside the car afterwards → clipped | `6b0b5c7` | On branch (logging) |
| v3.2 — Open round runs pure PID | 2026-09-03 → 09-04 | Open round ignores the Pi steer — wall + gyro PID only; per-round `AngGiro` / `MOTOR_MAX`; `giroArmado` corridor-arm; front-wall approach slow-down; `TERMINANDO` finish | Open round doesn't need vision and was inheriting obstacle-round speed caps; a wide start-zone reading latched a false first turn — [ERR-05](#err-05--ultrasonic-beam-cone-bounces-off-the-corner) | `626fc91`, `13e05c1` | On branch |
| v3.3 — gyro heading-hold by default | 2026-09-05 | On a clean straight the gyro steers; vision steers only while a pillar of ours is present. `RECUPERANDO` made non-interruptible; proportional wall override (`wallPanic`) | Small dodges left the chassis 20–30° crooked and the car drifted into a wall (runs 679–690); run 700 = first clean 12-corner run | `9c4b75e` era | Shipped |
| v3.4 — start from the parking lot (`INICIO`) | 2026-09-09 | Pi measures the magenta share at the button press and sends `inicio=1`; ESP32 drives a scripted S-exit | The Obstacle Challenge may start inside the lot | `6a713e3` | Shipped |
| v3.5 — floor-referenced color correction | 2026-09-12 | Per-frame gains so the white mat matches a reference color | A darker room pushed the orange tape into the red range — [ERR-15](docs/engineering-log.md#err-15--in-a-darker-room-the-orange-line-was-read-as-red) | `7bd353f` | Shipped |
| v3.6 — camera check before arming | 2026-09-14 | Start blocked (LED off) until the camera delivers real frames | Run 860 drove 19 s with a blind camera — [ERR-12](docs/engineering-log.md#err-12--camera-blackout-mid-run) | `486cc4c` | Shipped |
| v3.7 — obstacle-memory merge guard | 2026-09-15 | A remembered pillar can't "reappear" where it physically couldn't be | Two reds across a corner merged into one (run 954) — [ERR-21](docs/engineering-log.md#err-21--two-red-signs-on-both-sides-of-a-corner-merged-into-one) | `8bfe4d0` | Shipped |
| v3.8 — red range for the new venue + B/R test | 2026-09-16 | Red hue 168–179 plus a blue/red ratio test against the pink walls | New venue: red pillars not detected at all (run 1013) — [ERR-14](docs/engineering-log.md#err-14--at-a-new-venue-red-signs-were-not-detected-at-all) | `e3784a8` | Shipped |
| v3.9 — parallel parking | 2026-09-12 → 09-17 | Lot found from the side-ultrasonic profile, reverse parallel park, heading trimmed against the wall | 15-point parking; perfect parks in runs 1025, 1052, 1064 | `cf28a0f`, `8ef47d0` | Shipped |
| **Release `v1.0-nacional`** | 2026-09-19 | Code raced at the national final — **1st place** | — | `d5cc66d` | Released |
| v3.10 — ratio tests + corner hysteresis | 2026-09-22 | `RED_GR_MAX`, `GREEN_S_MIN_MED`; forward/reverse decision with ±6 cm hysteresis | Strong light: tape read as red, floor as green (run 1190) — [ERR-17](docs/engineering-log.md#err-17--strong-light-tape-read-as-red-pale-floor-read-as-green); maneuver flip at the boundary (run 1188) — [ERR-22](docs/engineering-log.md#err-22--the-corner-maneuver-changed-its-mind-at-the-last-moment) | `96145ba` | Shipped |
| v4.0 — steering Ackermann fix + 19-tooth pinion | 2026-10-06 | Rack joints 43 → 47 mm, tie rods 18.13 mm, pinion 14 → 19 teeth | Anti-Ackermann (39.5° / 42.8°) and only ~37° of steering — [§2.4](#24-steering--rack-and-pinion-with-ackermann-geometry) | `844195e` | Validated in CAD |
| v4.1 — Raspberry Pi 5 + camera calibration | 2026-10-06 → 10-07 | Pi 5 16 GB + Active Cooler; `format=BGRx` capture; lens-shading table for our lens | Pi 4 compute-bound at 14–18 fps and throttling at 84 °C; magenta ring on the Pi 5 — [§3.4](#34-main-computer--raspberry-pi-5-v2) | `844195e` | On branch |
| v4.2 — VL53L1X ToF ×4 | 2026-10 | Front, left, right, rear on one I²C bus with XSHUT re-addressing | Front ultrasonic phantom echoes — [ERR-19](docs/engineering-log.md#err-19--phantom-echoes-from-the-front-ultrasonic) | `844195e` (test sketches) | Bench test |

### 5.4 Risk analysis

| Risk | Likelihood | Impact | Mitigation |
|---|---|---|---|
| HC-SR04 spike reading | Medium | Medium — brief PID disturbance | EMA on all channels; 5-sample median on the front channel; cascade inner loop dampens |
| Gyro drift over 3 laps | Low | Medium — heading offset grows | 1°/s deadband; heading zeroed after every turn; startup bias calibration |
| Camera mount shifts after BEV calibration | Low | High — warped top-view, wrong centerline | Rigid printed camera frame; recalibrate if the mount is touched; reprojection-error check in `calibrate.py` |
| Can leaves FOV mid-dodge → ghost obstacle | Medium | Medium — phantom keep-out | Confidence decay; prune-on-pass; memory disabled during turns |
| UART packet delayed by OpenCV load | Medium | Low — one stale command | ESP32 reuses last command; 800 ms timeout → autonomous wall+gyro fallback |
| Corner missed / mis-counted | Low | High — wrong lap count or direction | Conservative thresholds; 2 s cool-down; `prio`/`mem` block detection while dodging; front-sensor debounce in the Obstacle round |
| False first turn from a wide start-zone reading (Open round) | Medium | High — wrong direction latched for the whole run | `giroArmado`: corner detection stays disabled until both walls read < 100 cm for 3 frames; timers re-anchored to roll-off |
| MANIOBRA runs the car into the outer wall | Medium | High — DQ | Forward/reverse chosen from measured outer-wall distance; reverse-timeout fallback; optional post-maneuver back-off |
| H-bridge damage from direction reversal under load | Low (mitigated) | High — dead driver | Motor-coast phase inserted before every direction change (learned the hard way) |
| Servo driven into its end stop | Low | Low | Firmware clamps servo command to 20°–150° |

### 5.5 Failure & Incident log

Post-mortems for the failures that changed the design — what happened, the confirmed or suspected root cause, and what shipped in response. Several of these are the "learned the hard way" behind a row of the risk table in [§5.4](#54-risk-analysis).

#### ERR-01 — VL53L0X lost the black wall past 70 cm

| | |
|---|---|
| **First seen** | 2026-05, first wall-following bring-up |
| **Setup** | Two VL53L0X, one per side — the same left/right wall-distance job the HC-SR04s do now. |
| **Symptom** | Against the matte-black outer wall the effective range collapsed: past ~70 cm the sensor stopped returning correct distances. White walls read to spec. |
| **Impact** | No usable lateral reference on the black-walled portions of the track — roughly half the perimeter. |
| **Root cause** | The 940 nm IR is absorbed by the matte-black surface; too little returns for a time-of-flight solve. A single sensor on the bench reproduced it, so not a wiring or I²C fault. |
| **Fix** | Switched both channels to HC-SR04 ultrasonic (`61544cb` era) — sound reflects off any surface regardless of colour. Traded ±3 mm for ±15 mm and closed the gap in software (EMA on all channels, a 5-sample median on the front channel, the cascade PID). |
| **Status** | Resolved. Trade-off in [§5.2](#52-key-engineering-trade-offs). |

#### ERR-02 — wall error goes blind at high yaw

| | |
|---|---|
| **First seen** | 2026-05 — one of the earliest problems, open-round bring-up |
| **Symptom** | On corner entry and recovery the car kept drifting into a wall even though the PID output stayed small and stable. |
| **Root cause** | The HC-SR04's ~15° beam cone hits the wall obliquely once the chassis is yawed; both sensors over-report by similar amounts, so `distL − distR` sits near zero while the car is visibly crabbing toward one wall. This is inherent to the sensor geometry and is **still true today**. |
| **Fix** | The cascade PID stops the car *acting* on the blind error: the **outer** loop turns lateral wall error into a target heading, the **inner** loop drives the servo to that heading from the **IMU** ([§4.6](#46-cascade-pid-always-running-underneath)). At high yaw the wall term is unreliable but the inner loop is still steering on a good heading signal, so the car tracks true and re-centres once the walls read cleanly again. |
| **Status** | Mitigated by design — the sensor limitation remains; the IMU inner loop is what keeps it from mattering. This cascade is also the fallback / RECUPERANDO / CRUCERO law and the blend term in SIGUIENDO. |

#### ERR-03 — wide-angle NoIR lens put a red cast on every frame

| | |
|---|---|
| **First seen** | 2026-07, after the lens swap; corrected on return, 2026-08-07 |
| **Change that caused it** | Moved from a ~63° lens to a ~120° wide-angle lens to see far enough ahead to react to a pillar and read the corner on the same frame. The wide lens has no IR-cut filter (NoIR). |
| **Symptom** | Every frame came out heavily red-tinted. HSV masks for the floor, the orange line and the red/green pillars all broke. |
| **Root cause** | With no IR-cut filter the sensor integrates near-IR the eye doesn't see; on this sensor it lands mostly in the red channel. |
| **Fix** | Pinned the libcamera pipeline to fixed white-balance — `libcamerasrc awb-enable=false colour-gains=<1.2,1.5>` — so auto-WB can't chase the cast, then re-tuned the red/green HSV ranges on the corrected image (`945c2f1`, 2026-08-07, and the `vision.py` range passes after it). |
| **Status** | Resolved on the Pi 4. The wide FOV is now a net win — more track and obstacle zone per frame. |
| **v2 update (Raspberry Pi 5)** | The Pi 5 has a different image processor and tuning. With fixed gains only, the frame edges showed a strong **magenta ring** (corners R/G ≈ 1.31–1.40 on a white sheet). Root cause: the factory lens-shading table (ALSC) is made for the stock lens and *raises* red at the corners. Fix: new ALSC table calibrated for our lens from 5 photos of a white sheet with the official tool (`rpi-ctt`), brightness part symmetrized, shipped as [`camera_tuning/imx219_noir_wro_pi5.json`](src/RASPI/cam/camera_tuning/README.md) + gains `<1.10,1.51>`. Result: R/G and B/G = 1.00 at the center and at all corners. See [ERR-29](docs/engineering-log.md#err-29--raspberry-pi-5-magenta-ring-at-the-frame-edges). |

#### ERR-04 — TB6612 and motor destroyed by a reversal with no coast delay

| | |
|---|---|
| **First seen** | 2026-08 → 09, `SectionTurning` MANIOBRA bring-up |
| **Symptom** | While testing the maneuver, the code switched the motor from forward to reverse with no gap between the two. A current spike followed; **one TB6612 driver and one N20 motor were lost.** |
| **Root cause** | Software, not hardware: the forward → reverse transition energised the H-bridge in the opposite direction while the motor was still spinning. Back-EMF plus shoot-through current during the flip exceeded the driver's rating (classic "plugging"). |
| **Fix** | Every direction change in the firmware — forward↔reverse, in MANIOBRA and everywhere else — now passes through a mandatory motor-coast phase (`A1 = A2 = LOW`, `MANIOBRA_FRENO_MS = 300`) so the motor spins down before the opposite direction is energised (`9219f17`). |
| **Status** | Resolved. No recurrence since the coast phase went in. Risk table: "H-bridge damage from direction reversal under load". |

#### ERR-05 — ultrasonic beam cone bounces off the corner

| | |
|---|---|
| **First seen** | 2026-08, open-round corner tuning |
| **Symptom** | The car would sail past a corner opening — it "thought" it had not reached the end wall yet when it had actually passed the turn point some time earlier. |
| **Root cause** | The front HC-SR04's beam cone widens with distance; far from the end wall it catches the *corner* geometry and returns a longer bounce path, so the front distance reads larger than the true straight-ahead gap. Corner detection kept waiting. |
| **Fix** | The car slows to `VEL_APROX_CERRADA` once the front sensor drops below `FRONT_SLOWDOWN_CM` (60 cm) — more time to read *which* side opens before it is on top of the corner. Plus EMA + a 5-sample front-channel median to reject spikes, and a multi-frame confirmation before a turn is accepted. In the Obstacle round the same read drives `CRUCERO → MANIOBRA` instead of a continuous arc. |
| **Verification** | 10 complete open-round runs from varied start positions and field configurations after these changes. |
| **Status** | Resolved. |

#### ERR-06 — the car pivoted in place instead of arcing

| | |
|---|---|
| **First seen** | 2026-08-28, sessions ~orillas 414–416, right after the frame-rate doubled ([ERR-08](#err-08--raspberry-pi-undervoltage-from-undersized-power-wiring)) |
| **Symptom** | Approaching a can, the car rotated on the spot instead of driving a curve around it. The can's `y` in the BEV barely moved (≈ 40 mm/s) — turning, not translating. RECUPERANDO then never fired (the memory never saw the can go behind the axis) so the car dug deeper in. |
| **Root cause** | (1) the obstacle steer term jumped to ±0.9 — near full lock — which pivots this chassis at cruise PWM; (2) `LOOKAHEAD_MIN_PX = 60` saturated the Pure Pursuit geometry, and the adaptive look-ahead / steer-gain keyed on **Euclidean** distance, so a can level with the car but off to the side kept those relaxed and the car drove past the point it should have turned. |
| **Fix** | `LOOKAHEAD_MIN_PX` 60 → 78; adaptive look-ahead (100 → 78 px) and `_distance_steer_gain` (0.30 → 1.0) re-keyed on the **longitudinal** gap; on a confirmed pass the runtime calls `memory.forget_color_obstacles()` so the centerline un-bends and the car eases out (`1daf563`). |
| **Verification** | Session orillas 417: dodge steer ±0.4–0.7, the can's `y` advanced through the pass = arc not pivot, both cans cleared, all 12 turns completed. |
| **Status** | Resolved. |

#### ERR-07 — RECUPERANDO trigger tied to assumed linear speed

| | |
|---|---|
| **First seen** | 2026-08-28, on-track (`f24c547` geom v1, `25d0565` geom v2) |
| **Symptom** | The recover-into-lane state fired either too early — nosing into the can it was meant to have cleared — or seconds too late, after the car had already straightened badly. Worst whenever the pass needed a large heading change. |
| **Root cause** | The trigger anchored the can's position when first seen and dead-reckoned it forward using an **assumed linear speed** through a bicycle model. With no measurement feedback the anchor drifted 200–400 mm in 1–2 s, and a hard dodge — car rotating, barely translating — broke the speed assumption entirely. `SPEED_SCALE` at 1.0 / 0.35 / 0.60 were all wrong somewhere. |
| **Fix** | Retired the anchor (`52549c8`). `_measured_recup_trigger` reads state that is already measured: **ARM** when the centerline's avoidance weight near the axis has been high for several frames (snapshot the heading), **CLEAR** when the rolling memory places no can in the path, fire only if **SKEW** — `|heading − snapshot| ≥ 25°`. A gentle dodge that straightens itself never stops for a recovery. |
| **Status** | Resolved. Finding a dodge shape that armed RECUPERANDO *reliably* was the single longest debugging effort of the obstacle round. Full history in [§4.4](#44-obstacle-handling-obstacle-challenge). |

#### ERR-08 — Raspberry Pi undervoltage from undersized power wiring

| | |
|---|---|
| **First seen** | 2026-08 |
| **Symptom** | Frames processed poorly or not at all; the Pi would sometimes power off mid-run. Intermittent, load-dependent. |
| **Root cause** | ~0.3 V drop between the PCB 5 V rail and the Pi's input on undersized power leads. Under vision + steering load the Pi input sagged below its undervoltage threshold and it throttled or browned out. |
| **Fix** | Re-ran the Pi feed in 22 AWG. The rail held; the processing loop went from ~7 fps to ~14 fps. |
| **Follow-on** | The frame-rate jump then destabilised the evasion tuning — several knobs were expressed per-frame, and doubling the rate doubled their effect. Every per-frame parameter was re-scaled (iteration log v2.7); the pivot-trap ([ERR-06](#err-06--the-car-pivoted-in-place-instead-of-arcing)) surfaced in the same window. |
| **Status** | Resolved (wiring). Pi input voltage is now on the pre-run checklist. |

#### ERR-09 — separating "my straight" from "the next straight" *(open)*

| | |
|---|---|
| **First seen** | 2026-09, `SectionTurning` |
| **Symptom** | A can on the *next* straight, visible over the corner, is sometimes treated as an obstacle on the current straight (or vice-versa). Wrong classification → an unnecessary dodge, or a real can ignored. |
| **Current handling** | `corner_lines.py` tracks the orange corner line row-by-row in the BEV and labels each remembered can *mine* / *beyond* with asymmetric hysteresis (quick to start avoiding, slow to stop). Tried and reverted: locking onto the primary can by camera-bbox height (`601ea8d` … `ad4f71e`, 2026-09-02 — bbox too noisy frame to frame). |
| **Impact** | The main reason the obstacle round is not yet complete on every field configuration. Simple layouts pass reliably; a can straddling the corner sightline does not. |
| **Status** | **Open — active work.** |
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

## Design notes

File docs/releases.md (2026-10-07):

# Releases

Each competition corresponds to one release. A release is a git tag on the exact code that ran, plus these notes. To get the code of a release: `git checkout <tag>`.

| Release | Event | Date | Commit | Result |
|---|---|---|---|---|
| [`v1.0-nacional`](#v10-nacional--mexico-national-final) | WRO Mexico national final | 2026-09-19 | `d5cc66d` | 1st place, documentation 26/30 |
| [`v2.0-internacional`](#v20-internacional--in-progress) | WRO international final | 2026-12-08 to 12-10 | — | In progress |

---

## v1.0-nacional — Mexico national final

**Hardware**

| Item | Value |
|---|---|
| Main computer | Raspberry Pi 4 |
| Controller | ESP32 DevKit |
| Camera | Raspberry Pi Camera v2 + NoIR wide-angle lens (~120°), 640×480, fixed gains `<1.2,1.5>` |
| Distance | 3 × HC-SR04 (left, right, front) |
| IMU | MPU-6050 (gyro Z) |
| Drive | N20 50:1 + 2:1 gear stage, LEGO differential |
| Steering | SG90 servo, rack and pinion, 14-tooth module-1 pinion, rack joints 43 mm apart, ~37° inner wheel |

**Software**
- Vision on the Pi: floor-referenced color correction → red/green/magenta detection → bird's-eye view → corner lines → obstacle memory → corridor centerline → Pure Pursuit, at ~14–18 fps.
- ESP32 nine-state machine. Gyro heading-hold on clean straights; vision steers only while dodging.
- Obstacle Challenge: stop-and-turn corners (forward arc or reverse pivot). Open Challenge: continuous gyro-gated turn.
- Start from the parking lot (`INICIO`). Parallel parking (`ESTACIONANDO`).
- Hot start: the pipeline runs disarmed before the button, so the first sign is already tracked at the start.
- Camera brightness check before arming.

**Known issues at this release:** phantom front echoes (ERR-19); heading drift built up by dodges (ERR-23); performance depends on the battery voltage window (ERR-11); the forward/reverse decision could flip at the 28 cm boundary (ERR-22, fixed after the event).

---

## v2.0-internacional — in progress

Changes since `v1.0-nacional` (details in the [README](../README.md#13-what-changed-for-the-international-final-v2) and the [engineering log](engineering-log.md)):

| Area | Change | Status |
|---|---|---|
| Steering | Ackermann corrected (rack joints 47 mm, tie rods 18.13 mm); 19-tooth pinion; 53.1° / 37.0° at full lock | Validated in CAD; track test pending |
| Computer | Raspberry Pi 5 (16 GB) + Active Cooler; same pipeline at 40–41.5 fps | Port in progress: frame-rate constants pending |
| Sensors | 4 × VL53L1X ToF (front, left, right, rear) | Bench test |
| Vision | Ratio tests against orange tape and pale floor (`RED_GR_MAX`, `GREEN_S_MIN_MED`) | Validated (replay over 6 runs) |
| Camera | Pi 5 capture fix (`format=BGRx`) + lens-shading table for our lens + gains `<1.10,1.51>` ([ERR-28](engineering-log.md#err-28--raspberry-pi-5-the-race-camera-pipeline-would-not-start), [ERR-29](engineering-log.md#err-29--raspberry-pi-5-magenta-ring-at-the-frame-edges)) | Validated on a white sheet; pillar thresholds pending |
| Corners | Forward/reverse decision with hysteresis and a shared latch | In repository; track test pending |
| Firmware | Single parking-mode switch (`PARK_MODO`), dead parameters removed | In repository |

The release is tagged when the validation matrix in [testing.md](testing.md#62-validation-matrix-for-v2-international-final) passes.

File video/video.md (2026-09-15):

# FoxRobotics — WRO 2026 Future Engineers

## Open Challenge — 3 laps autonomous

Open Challenge (https://youtu.be/orP-BNSG-6s)

[https://youtu.be/orP-BNSG-6s](https://youtu.be/orP-BNSG-6s)

## Obstacle Challenge — 3 laps autonomous with obstacles

Obstacle Challenge (https://youtu.be/VI6V6hTf_HE)

[https://youtu.be/VI6V6hTf_HE](https://youtu.be/VI6V6hTf_HE)

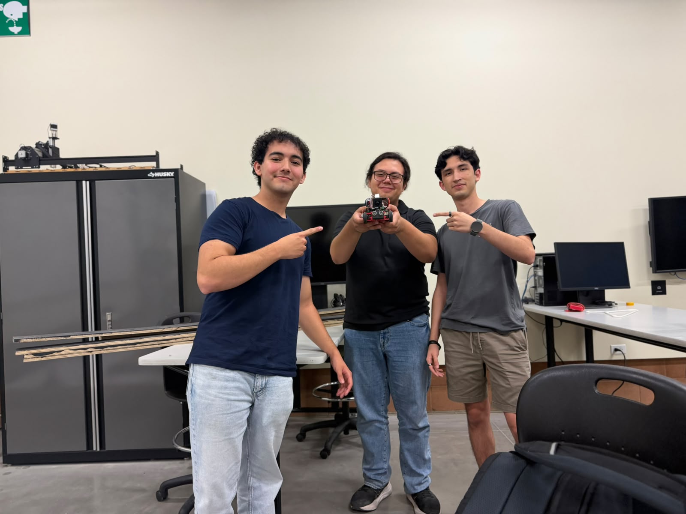
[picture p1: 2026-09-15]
t-photos/FunPicture.jpeg

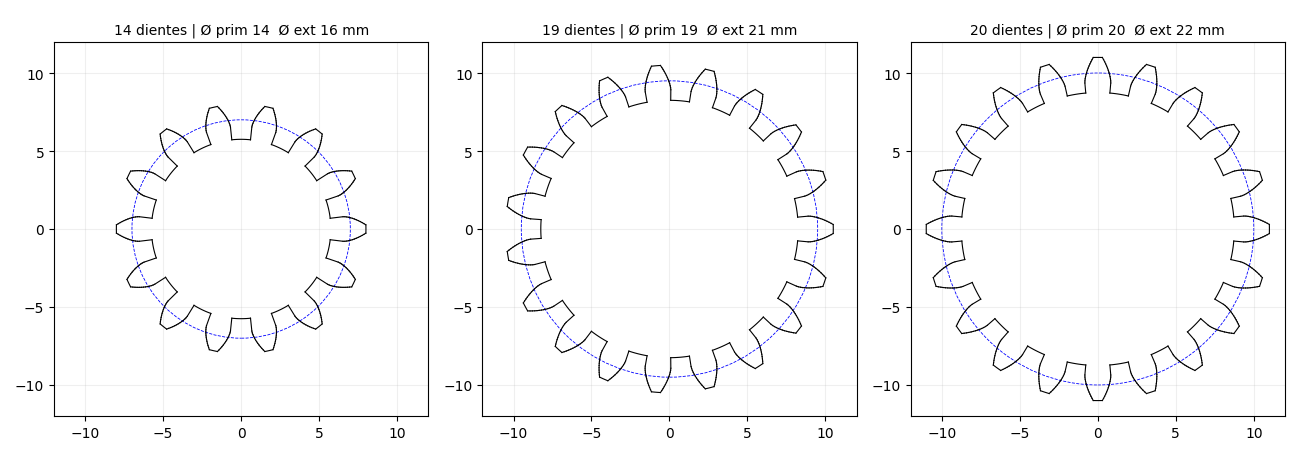
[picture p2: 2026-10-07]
Mecanica/Engranes/preview_pinones.png

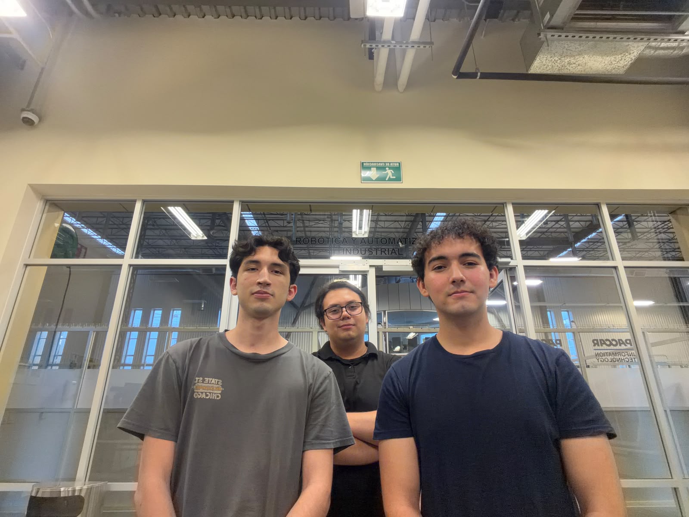
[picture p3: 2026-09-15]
t-photos/TeamPicture.jpeg

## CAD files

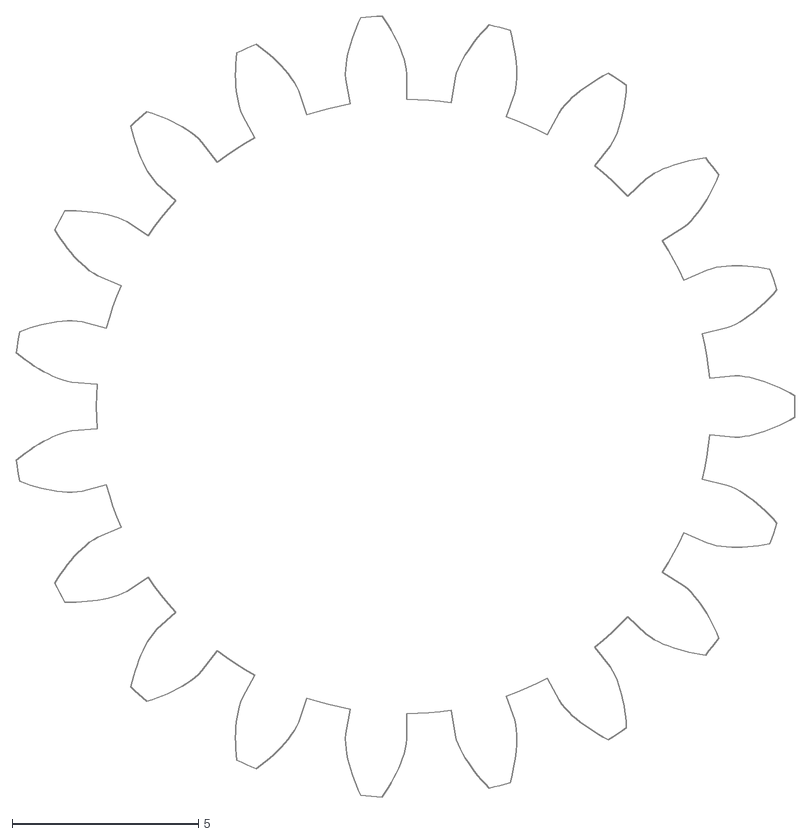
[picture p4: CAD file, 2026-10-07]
Mecanica/Engranes/pinon_m1_Z19.dxf
20.9 x 21.0

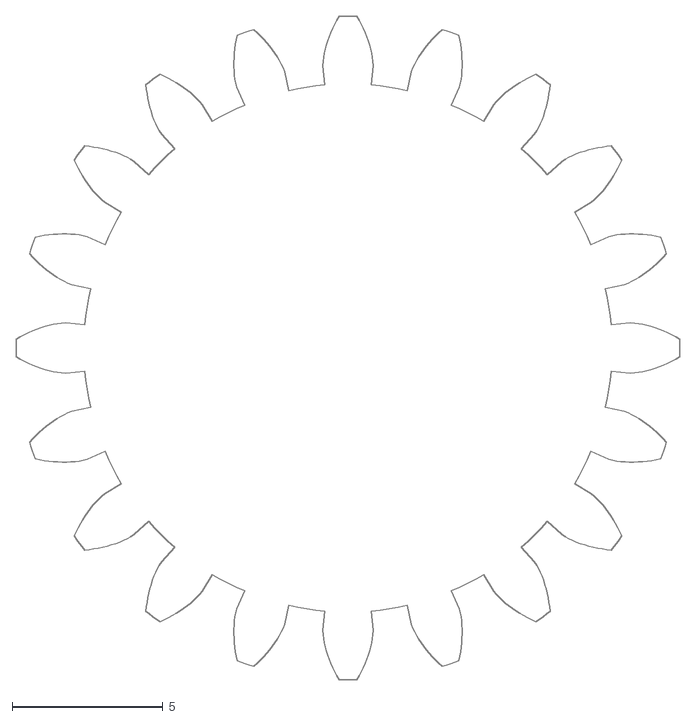
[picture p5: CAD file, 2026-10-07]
Mecanica/Engranes/pinon_m1_Z20.dxf
22.0 x 22.0

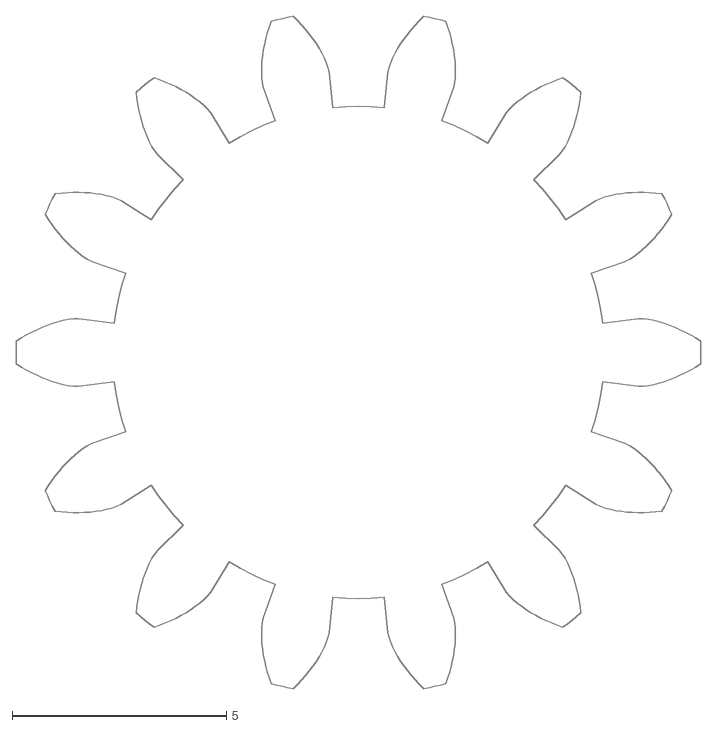
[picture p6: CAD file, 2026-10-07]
Mecanica/Engranes/pinon_m1_Z14.dxf
16.0 x 15.7

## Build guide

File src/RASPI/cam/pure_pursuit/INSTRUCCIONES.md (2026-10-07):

 # Pure Pursuit — Instrucciones de uso

Todos los comandos se corren desde `src/RASPI/cam/`.

---

## 1. Calibrar la cámara (una sola vez)

Necesitas la cámara montada en su posición final en el robot, apuntando al piso.

Coloca 4 marcadores físicos (papel, cinta) en el suelo en estas posiciones relativas al eje delantero del robot:

| Punto | Lateral | Adelante |
|---|---|---|
| A | 10 cm izquierda | 20 cm |
| B | 10 cm derecha | 20 cm |
| C | 15 cm izquierda | 38 cm |
| D | 15 cm derecha | 38 cm |

```bash
python -m pure_pursuit.calibrate
```

1. Se abre una ventana con la cámara en vivo
2. Presiona `C` para congelar el frame
3. Haz clic en los 4 marcadores en orden: A → B → C → D
4. Se abre una segunda ventana con la vista BEV en tiempo real — verifica que se vea bien
5. Presiona `S` para guardar → genera `pure_pursuit/bev_calib.npz`
6. Presiona `R` para rehacer si los puntos quedaron mal

> Si mueves o cambias el ángulo de la cámara, repite este paso.

---

## 2. Calibrar colores (antes de cada competencia / si cambia la luz)

El detector **no usa rangos RGB**. Usa HSV: conos en `vision.py` (`COLOR_RANGES`),
cinta naranja / rosa / piso en `config.py`. La cámara tiene el balance de blancos
apagado, así que otra luz corre los tonos. `color_corr.py` intenta devolverlos
al color del cuarto de pruebas midiendo el piso; si el piso está quemado no
puede, y hay que medir a mano.

Para el servicio (tiene la cámara tomada):

```bash
sudo systemctl stop wro-runtime && sleep 4
```

Ventana (recomendado): pinta el cono/cinta/pared o pulsa `a` para auto-detectar
por RGB (dominancia de canal, aguanta el cambio de luz). Te imprime HSV listo
para pegar:

```bash
python3 -m pure_pursuit.calibra_luz --gui
```

- `1` rojo  `2` verde  `3` naranja  `4` rosa
- click + arrastrar = muestrear  |  `a` = auto-detectar el color activo
- `p` imprime ese color  |  `s` imprime todos  |  `c` prende/apaga color_corr
- overlay: lo que AGARRAN los rangos actuales vs lo que estás midiendo

Sin pantalla (SSH), con un cono rojo y uno verde enfrente:

```bash
python3 -m pure_pursuit.calibra_luz --vivo --sugerir
```

Sobre una corrida grabada (panel izquierdo del HUD = lo que ve la visión):

```bash
python3 -m pure_pursuit.calibra_luz --avi videos_orillas/orillasNNNN.avi --sugerir
```

Dónde pegar lo que imprime:

| Color | Archivo |
|---|---|
| rojo / verde | `vision.py` → `COLOR_RANGES` (y `LINE_CONE_HSV` en `config.py`) |
| naranja (cinta) | `config.py` → `LINE_ORANGE_HSV` / `LINE_CORE_HSV` |
| rosa (estacionamiento) | `config.py` → `PARK_PINK_HSV` |
| piso BGR | `config.py` → `COLOR_CORR_FLOOR_REF_BGR` |

Después: `sudo systemctl start wro-runtime` (nunca `restart`: deja la CSI colgada).

---

## 3. Probar solo la visión (sin robot, sin ESP32)

Útil para verificar que la BEV y la centerline se ven bien antes de conectar todo.

```bash
python -m pure_pursuit.test_vision
```

Con un video grabado en lugar de cámara en vivo:
```bash
python -m pure_pursuit.test_vision --video ruta/al/video.mp4
```

Lo que deberías ver:
- Ventana izquierda: cámara con los obstáculos detectados (rojo/verde marcados)
- Ventana derecha: BEV con la centerline en cyan, punto look-ahead en amarillo, robot en naranja
- Texto arriba: `pp=ON`, ángulo de dirección, cantidad de puntos del path

Presiona `S` en cualquier momento para guardar un screenshot.
Presiona `ESC` para salir.

---

## 4. Correr en el robot real

### Requisitos previos
- `bev_calib.npz` generado (paso 1)
- ESP32 con `PurePursuit.ino` ya flasheado
- Pi conectada al ESP32 por Serial2 (RX=17, TX=16)

### Comando

```bash
python -m pure_pursuit.runtime
```

### Secuencia de arranque automática
1. LED en GPIO27 enciende → Pi lista
2. Espera que presiones el botón en GPIO17
3. Calienta la cámara ~2 segundos
4. Manda `READY` al ESP32 → ESP32 responde y arranca motores
5. Loop: cámara → BEV → centerline → Pure Pursuit → serial al ESP32

### Flags útiles

```bash
# Sin ventana (en competencia sin monitor)
python -m pure_pursuit.runtime --no-window

# Grabar video de lo que ve la cámara
python -m pure_pursuit.runtime --no-window --record-orillas

# Puerto serial diferente (si usas adaptador USB)
python -m pure_pursuit.runtime --serial-port /dev/ttyUSB0
```

---

## Resumen de archivos

| Archivo | Para qué |
|---|---|
| `calibrate.py` | Calibrar la homografía BEV con la cámara real |
| `test_vision.py` | Probar visión + centerline sin robot ni serial |
| `runtime.py` | Runtime completo para competencia |
| `config.py` | Todos los parámetros ajustables (HSV, lookahead, gains) |
| `bev_calib.npz` | Archivo de calibración generado por calibrate.py |

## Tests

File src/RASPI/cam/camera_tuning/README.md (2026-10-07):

# Camera tuning — Raspberry Pi 5 + Camera v2 with a wide-angle lens

## The problem

Our wide-angle lens adapter has **no infrared-cut filter**. With the stock processing, the image looks reddish, and the edges of the frame show a **magenta ring**, even when the camera looks at a white sheet. On a plain white sheet, the corners measured R/G ≈ 1.31–1.40 and B/G ≈ 1.26–1.35 against ≈ 1.0 at the center.

The ring is dangerous for the robot: magenta is close to the pink parking-lot walls and to the red traffic signs.

White-balance gains alone can't fix it, because they scale the whole image by the same amount. The ring is a **lens shading** problem: the camera's processor corrects the color of each zone of the image with a table (ALSC, Auto Lens Shading Correction), and the factory table is made for the stock lens. For the red channel it even *raises* the corners (×1.33 relative to the center), which is the opposite of what our lens needs.

## The fix (two steps)

1. **A lens shading table for our lens.** We photograph a uniformly lit white sheet, and the official Raspberry Pi Camera Tuning Tool (`rpi-ctt`) computes a new table from those photos. The table goes into a copy of `imx219_noir.json`, the tuning made for cameras without an IR filter. Result: [`imx219_noir_wro_pi5.json`](imx219_noir_wro_pi5.json).
2. **Fixed white-balance gains** measured on the same white sheet: `colour-gains=<1.10,1.51>` (red, blue), with automatic white balance off.

`vision.open_camera()` loads this tuning file through `LIBCAMERA_RPI_TUNING_FILE` and applies the gains, but only on a Pi 5. On a Pi 4 it keeps the v1 configuration.

**Result (2026-10-07, white sheet, ~3700 K light):** R/G and B/G = 1.00 ± 0.01 at the center **and** at all four corners.

## How to redo it (≈10 minutes, for example during practice time at a new venue)

1. Stop anything that uses the camera (`sudo systemctl stop wro-runtime`; the camera can only be opened by one process).
2. Fill the **whole frame** with a white sheet, lit evenly by the venue light: no shadows, no glare, no folds. Out of focus is fine. Check it live with [`pure_pursuit/cam_web.py`](../pure_pursuit/cam_web.py) at `http://<pi>:8080`.
3. Take 5 raw photos under the same light (`python camera_tuning/captura_alsc.py 5` on the Pi; it writes to `~/alsc_cal/`). It measures the color temperature, sets the exposure a bit below automatic so nothing saturates, and saves `alsc_<CT>k_<n>.dng`.
4. Compute the table:
   ```bash
   cp /usr/share/libcamera/ipa/rpi/pisp/imx219_noir.json base_noir.json
   ~/ctt_venv/bin/ctt --alsc-only -i ~/alsc_cal -o out --update base_noir.json
   ```
   The `rpi-ctt` package is installed in `~/ctt_venv` (`pip install rpi-ctt`).
5. Copy `base_noir.json` over `imx219_noir_wro_pi5.json` and run `python simetriza_luminancia.py imx219_noir_wro_pi5.json`. Then open `cam_web.py --tuning <that file>`, put the sheet in the yellow box, press **"Balancear con la hoja blanca"**, and copy the gains into `vision.py`.
6. Re-check the color thresholds on real signs and lines (`calibra_luz.py`). The HSV ranges were tuned on the Pi 4 image.

## Notes

- One light, one table. With automatic white balance off, a single color temperature gives predictable behavior. If the venue light is very different (e.g. fluorescent vs LED), redo the calibration there.
- **Brightness table symmetrized.** The brightness part of the table came out asymmetric (corners ×2.0 at the bottom, ×4.3 at the top): it was also correcting the uneven light on the sheet, which was darker at the top. Lens vignetting is symmetric around the center, so [`simetriza_luminancia.py`](simetriza_luminancia.py) averages the brightness table with its mirror images. That keeps the lens part and cancels the lighting gradient. Result: ×2.93 at every corner, almost the same as the factory table (×2.96). So the lens darkens the edges about as much as the stock lens; what it changes is the **color** of the edges. The color tables are not touched. Run it after step 4 every time.
- A diffuser gives an even flat field without this step: put the sheet flat **on** the lens, pointing at the light.
- Dust on the lens shows up as dark spots in the flat-field photos. Clean the lens before calibrating.
- References: [Raspberry Pi CTT (`rpi-ctt`)](https://pypi.org/project/rpi-ctt/), [Arducam — Lens Shading Calibration](https://docs.arducam.com/Raspberry-Pi-Camera/Native-camera/Lens-Shading/), [OpenFlexure — lens shading correction](https://openflexure.discourse.group/t/lens-shading-correction-for-raspberry-pi-camera/682).

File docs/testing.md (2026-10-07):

# Testing and Validation

This document describes how we test the robot, what we measure, and the results we have so far. Results are tied to a code version (commit) so they can be reproduced. A failed run is kept in the record, because it tells us what to change next. Decisions and failures found through these tests are in the README failure log ([§5.5](../README.md#55-failure--incident-log), ERR-01 to ERR-09) and in the [engineering log](engineering-log.md) (ERR-10 onward).

## 1. What every run produces

Every run is recorded automatically. Nobody has to remember to start a recording.

| Evidence | Where | What it is used for |
|---|---|---|
| Video `orillasNNN.avi` | `~/FoxRobotics/videos_orillas/` on the Pi | Camera and bird's-eye view side by side, with the debug overlay: detections, path, steering, state, stage timings. MJPG format, so it still plays if the run is cut off. |
| Pi journal | `journalctl -u wro-runtime.service` | Every message sent to the ESP32 and every ACK received: heading, state, the three ultrasonic distances, maneuver choice, parking phase. It also logs the decision traces `[RECUP]`, `[LINEA]`, `[MEMREJ]` and `[COLOR]`. Persistent across reboots on the Pi 5. |
| Run report | `python scripts/reporte_run.py --pi` | Turns the journal of the last run into a per-corner summary: states, heading at each corner, forward/reverse maneuver, distances, parking phases. Optional HTML output. |

Run numbers (`NNN`) are global and increase with every run, so a run number identifies one video plus one journal section.

## 2. Test workflow

1. **Record the configuration.** Commit hash on the Pi (`git log -1`), challenge type and race length in the firmware (`rondaObstaculos`, `TURNS_PER_RACE`), battery voltage, direction, and sign layout.
2. **Pre-run checks** (section 4). A run that fails a check doesn't count.
3. **Run without touching anything.** We never change parameters during a run.
4. **Measure.** Score by the official table, time, interventions, contacts with signs or walls, signs moved, corners completed, parking result, and the voltage after the run.
5. **Diagnose every failure from evidence.** Find the frame in the video, then the matching log line, and name the cause before changing code. A fix without an identified cause is not merged.
6. **Change one thing at a time.** Then repeat the same layout in both directions. When a change touches perception or memory, we first **replay** recorded runs through the old and the new code (section 5) and compare frame by frame.
7. **New behaviors start in log-only mode.** A new detector or trigger first only logs what it *would* do, next to the existing one. It gets control after the logs show it is right. We adopted this rule after ERR-25.

## 3. Metrics

| Metric | Why |
|---|---|
| Score and time per round | What the competition ranks |
| Corners completed out of 12, and laps | Main reliability measure |
| Signs touched or moved | Moving a sign out of its area costs points; we count every contact |
| Heading error at the end of each maneuver (`ang`) | Measures drift and maneuver accuracy (−7.5° ± 0.9° bias found this way, ERR-23) |
| Heading swing during a dodge | Detects over-rotation (battery ERR-11, camera tilt ERR-18) |
| Closest wall distance per straight (`dL`, `dR`) | Margin before contact |
| Detections per run, real vs false | Checked by eye on cropped detections when tuning vision |
| Loop rate (fps) and `get_throttled` | Compute and power health |

## 4. Pre-run checklist

- [ ] Battery between **11.70 and 12.15 V** (ERR-11). Discharge a fresh charge first.
- [ ] `vcgencmd get_throttled` = `0x0` (ERR-08).
- [ ] Firmware flashed with `TURNS_PER_RACE = 12` and the right `rondaObstaculos` value for the round. Test builds use 4 turns.
- [ ] Status LED on: the camera passed its brightness check (ERR-12).
- [ ] Camera level and lens seated (ERR-18; run 840 had a loose, blurry lens).
- [ ] At a new venue: run `calibra_luz.py` during practice and check red, green, orange and magenta on real frames (ERR-14).
- [ ] Remote desktop, Wi-Fi, Tailscale and Claude Remote Control **off** for official rounds (rule 11.10).
- [ ] After any `git pull` on the Pi: `sync` before unplugging (ERR-10).

## 5. Replay testing

Most vision and memory changes are validated before touching the track, by feeding recorded runs through the new code:

- **Detection replay:** run `vision.detect_on` over every frame of a recorded `.avi` (the camera half of the overlay is exactly what the detector saw). Count detections before and after, and inspect the rejected crops. Used for ERR-15 and ERR-17 (6 runs).
- **Memory replay:** feed the real `ObstacleMemory` with the logged detections and ACKs. It reproduces the logged memory state at 93–100% of frames. Used for ERR-21 (16 runs, 37,774 frames).
- **Performance replay:** run the real `runtime_nuevo.py` with a recorded video as the camera and no ESP32. Used for the Raspberry Pi 5 port (40–41.5 fps on run 1190).

Replay can't test anything that depends on the car moving differently, such as a new steering decision. Those changes need track runs.

## 6. Results

### 6.1 Reference runs (v1, before the national final)

| Run | Date | Round | Dir. | Result | Notes |
|---|---|---|---|---|---|
| 700 | 2026-09-05 | Obstacle | — | 12/12 corners, clean | First clean run after the gyro-default change (DEC-04) |
| 834 | 2026-09-10 | Obstacle | CCW | Clean dodges | Reference for the battery window (ERR-11) |
| 842 | 2026-09-11 | Obstacle | CCW | Over-rotated dodges | Fresh battery; same code as 834 |
| 845 | 2026-09-11 | Obstacle | — | Red sign grazed (lap 2) and moved (lap 3) | ERR-24 |
| 860 | 2026-09-12 | Obstacle | — | Crash, no turn | Camera blind for 19 s (ERR-12) |
| 1013 | 2026-09-16 | Obstacle | — | Red sign not dodged | New venue lighting (ERR-14) |
| 1025 | 2026-09-16 | Obstacle | — | Perfect parallel park | Reference parking constants |
| 1047 | 2026-09-16 | Open | — | 12/12 corners | Phantom front echoes in ~20% of straight frames (ERR-19) |
| 1064 | 2026-09 | Obstacle | CCW | **Full clean round + parallel park** | Start from the lot, 12 corners, parked with 0.9° heading error |
| National final | 2026-09-19 | Both | — | **1st place** | Release `v1.0-nacional` |

### 6.2 Validation matrix for v2 (international final)

For each configuration we run both directions and three start sections. A configuration passes only with **3 consecutive clean runs**.

| Run | Round | Dir. | Start section | Layout | Score | Time | Contacts | Interventions | Battery (V) | Commit | Status |
|---|---|---|---|---|---:|---:|---:|---:|---:|---|---|
| OPEN-01 | Open | CW | | | | | | | | | To run |
| OPEN-02 | Open | CCW | | | | | | | | | To run |
| OBS-01 | Obstacle | CW | | | | | | | | | To run |
| OBS-02 | Obstacle | CCW | | | | | | | | | To run |

### 6.3 Sensor-fault behavior

| Fault | What the robot does | Evidence | Status |
|---|---|---|---|
| Pi silent for > 800 ms | The ESP32 falls back to wall-following + gyro and keeps driving | Firmware `piTimeoutMs` | In code, not fault-injected |
| Camera black or frozen before the start | The camera is reopened; the LED stays off and the start is blocked until real frames arrive | Run 860 analysis, `486cc4c` | Validated |
| Camera black **during** a run | Not detected; the car drives on stale vision | Run 860 | Known limitation |
| `RECUPERANDO` never reaches its heading | It times out, then continues | Firmware `timedOut` | In code |
| Front ultrasonic phantom echo | Corner trigger needs consecutive readings, and a minimum time between maneuvers | ERR-19 | Mitigated |
| Car too close to a side wall | Proportional push away from it (`wallPanic`, below 18 cm) | ERR-20 | Validated |

## 7. Known limitations

- Speed is still open-loop: the v2 encoder motor is mounted, but the firmware doesn't use the encoder yet, so maneuvers still depend on battery voltage (ERR-11). Next step: a speed loop on the ESP32 (hardware pulse counter) and distance-based maneuvers.
- Heading drifts within straights through the dodges, and is only corrected against a wall during parking (ERR-23).
- The obstacle memory rotates its map with the wrong sign (ERR-21). Other parts were tuned around it, so we left it until it can be re-validated.
- The bird's-eye calibration assumes a fixed camera angle. Any impact on the mount requires a check (ERR-18).
- On the Raspberry Pi 5 the main loop runs faster than the camera (40 vs 30 fps) and reprocesses repeated frames. Before racing it, the loop rate must be capped, or the per-frame constants rescaled (ERR-26).

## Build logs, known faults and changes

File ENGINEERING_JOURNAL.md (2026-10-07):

# FoxRobotics — Engineering Journal

> **Team:** FoxRobotics · **Event:** WRO 2026 Future Engineers — Self-Driving Car
> **Region:** México — Baja California

## Team & roles

| Member | Responsibility |
|---|---|
| **Erick Blanco** | Mechanical design; vehicle programming and control — both the Open and the Obstacle rounds |
| **Jesse Banda** | Vehicle programming, primarily computer vision; built the code structure the rest was developed on |
| **César Emiliano Ahumada** | Electrical bring-up and testing; schematic and PCB design |
| **Daniel Millán** | Coach |

Dated, chronological record of the build. It is the **timeline** companion to the two
thematic views in the [README](README.md):

- [§5.3 Iteration log](README.md#53-iteration-log) — structural changes by topic, with status.
- [§6.5 Milestones](README.md#65-milestones) — M1–M11 with acceptance criteria.
- [§5.5 Failure & Incident log](README.md#55-failure--incident-log) — post-mortems `ERR-01…ERR-09`.

Where an entry maps to one of those, it is cross-referenced rather than repeated.

**Sources & conventions**

- The **pre-repo period** (late March – early May 2026) is reconstructed from the team's
  design notes and is marked *(reconstructed)*.
- From 2026-04-13 onward, entries are anchored to **git history on `main`** (short hashes
  link into the log) and to the numbered on-track test sessions (`orillasNNN`) — the
  session counter has incremented on every integrated run since June 2026 and is now
  around **700**, so most tuning happened between commits, not in them.
- **branch** marks work implemented on a feature branch (`Workin`, `SectionTurning`,
  `ParedCenterline`) and not yet merged to `main`.

---

## Phase 0 — Vehicle design & per-peripheral bring-up *(reconstructed; pre-repo)*

**Focus:** one reliable vehicle, architecture fixed before any code — Raspberry Pi 4 for
vision, ESP32 for all real-time I/O ([README §1.1](README.md#11-design-goals)).

### 2026-03-30 → 04-05 — Semana Santa design week
A full week on the vehicle before anything else: SolidWorks CAD of the whole car, fit
checks and tolerance checks on every mating part, packaging the chassis around the
electronics (Raspberry Pi 4 first). Decisions locked here and never revisited: two-controller
split (Pi 4 + ESP32), rack-and-pinion Ackermann steering, rear-wheel drive with a printed
open differential, ~20 × 10 cm footprint for obstacle-field clearance.
→ [README §2](README.md#2-mechanical-design--mobility), [§2.4](README.md#24-steering--rack-and-pinion-with-ackermann-geometry).

### 2026-04 — Chassis, base wiring, PCB layout started
Chassis printed in PLA on a Bambu Lab A1 and assembled with LEGO axles/wheels
(**M1**). Base circuit designed and validated on a breadboard (**M3**). Custom PCB
laid out to fit the finished mechanical model — designed *after* the CAD, not before
(**M4**). → [README §3.3](README.md#33-pcb--wiring).

### 2026-04-13 → 04-27 — First commits: CAD + PCB
Repository created (git started well after the project did). CAD model, schematic, and
PCB shape committed; routing begun.
`283078e` · `ade099b` · `c9ce1e2` · `7e2a3d3` · `51ea239` (final PCB shape) · `f015e0d` (routing).

### ~2026-04-25 → 05-09 — Per-peripheral ESP32 bring-up
Each sensor and actuator bench-tested in isolation with a dedicated sketch, ESP32 only —
each HC-SR04, the servo, the DC motor, gyro read, serial echo
([`src/ESP32/TestCodes/`](src/ESP32/TestCodes/)) (**M2**). First combined controller
sketch alongside them. By 2026-05-09 this produced a **slightly functional Open-round
car running on the ESP32 alone** (no Raspberry Pi yet). `6474f65` (TestCodes +
FirstController).

---

## Phase 1 — First closed-loop Open Challenge run (May 2026)

**Focus:** get the car around the track on wall following alone.

### 2026-05-09 — First working Open-round controller
Single-loop PID on `distL − distR`, two VL53L0X ToF sensors, 3-state FSM
(`Controller_PI.ino`). First lap capability. `61544cb`.
→ [README iteration log "First firmware"](README.md#53-iteration-log).

### 2026-05 — `ERR-01`: ToF lost the black wall
Against the matte-black outer wall the VL53L0X range collapsed past ~70 cm; white walls
read fine. Reproduced on the bench with a single sensor, so not a wiring fault. **Both
channels switched to HC-SR04 ultrasonic** — traded ±3 mm for ±15 mm and closed the gap in
software later. → [README ERR-01](README.md#err-01--vl53l0x-lost-the-black-wall-past-70-cm).

### 2026-05 — `ERR-02`: wall error goes blind at high yaw
On corner entry the car drifted into a wall while the PID output stayed small: the
HC-SR04 beam cone hits the wall obliquely once yawed, both sides over-report, `distL − distR`
sits near zero. Motivated the **cascade PID** (outer wall→heading, inner heading→servo via
IMU) built over the next weeks. → [README ERR-02](README.md#err-02--wall-error-goes-blind-at-high-yaw),
[§4.6](README.md#46-cascade-pid-always-running-underneath).

### 2026-05-23 — Camera bring-up
Pi camera wired; track-edge (`detect_orillas.py`) detection and the BEV calibration tool
scaffolded; threaded recorder added so runs are reviewable. Many same-day iterations.
`21fe8df` · `5797487` · `345b430` (`record_orillas.py`).

### 2026-05-25 → 05-26 — Repo reorganized, first README
`src/` and `models/` restructured; first README written.
`6a448ca` · `ea70bfc` · `dde0543` · `a3b2fe6`.

---

## Phase 2 — Two controllers, one link (June 2026)

**Focus:** split vision and real-time control across the two processors and make the link
survive latency.

### 2026-06-04 → 06-05 — Integration pass + UART diagnostics
Vision, `wro_runtime.py`, and `Controller_PI.ino` wired end-to-end. UART framing tools
added (`diagnose_uart.py`, `test_serial_debug.py`, `test_uart_simple.py`); dead code
parked; `wro-runtime.service` drafted. `0a9251f` · `9169693` · `d6f677a` · `a8345dd`.

### 2026-06-08 → 06-09 — Two-controller split formalized + deploy infra
VNC for live view on the Pi; a self-hosted GitHub Actions runner and push-to-deploy CI;
an 800 ms timeout so a late packet makes the ESP32 reuse the last command instead of
stalling. `69f82a9` · `a065d78`.
→ [README §4.1](README.md#41-system-overview--two-controllers-one-link),
[§5.2 trade-off 1](README.md#52-key-engineering-trade-offs).

### 2026-06-11 → 06-13 — Pure Pursuit workspace
`FixedController` for the Open round (`711c6ec`); `pure_pursuit/` scaffold with
`INSTRUCCIONES.md` and `calibrate.py` (`95f3744`).

### 2026-06-22 — Centerline extraction + geometric Pure Pursuit
Floor-colour centerline in the BEV, first `PurePursuit.ino`, first `centerline.py`.
Replaces the reactive pillar-offset PID, which over-reacted near and under-reacted far.
`79706be` (camera-duplicate fix) · `e494d8c` (centre algorithm) · `556266b`.
→ [README iteration log v2.0](README.md#53-iteration-log),
[§4.3](README.md#43-vision-pipeline-raspberry-pi--pure_pursuit).

### 2026-06-25 — Last commit before the July break
`2b0f82d`. Repo quiet until 2026-08-07.

---

## Phase 3 — Wide lens & white balance (July – 2026-08-07)

### 2026-07 (first week) — Lens swap 63° → 120°
Wide-angle NoIR lens arrived in the first week of July, so the camera sees far enough
ahead to read a pillar and the corner on the same frame. The rest of that period went to
bench tests aimed at removing the reddish cast it introduced (see `ERR-03` below).

### 2026-08-07 — `ERR-03`: red cast on every frame
The NoIR lens has no IR-cut filter; every frame came out heavily red-tinted and all HSV
masks broke. Fixed by pinning libcamera white balance
(`awb-enable=false colour-gains=<1.2,1.5>`) and re-tuning the red/green ranges on the
corrected image. Also a first pass at a false-turn bug.
`9ada7a0` (FalseTurn bug) · `140051a` · `945c2f1` (RGB range cleanup).
→ [README ERR-03](README.md#err-03--wide-angle-noir-lens-put-a-red-cast-on-every-frame).

---

## Phase 4 — Sim, calibration, corner lines (2026-08-11 → 08-19)

### 2026-08-11 — Offline kinematic sim
`pure_pursuit_sim.py` (bicycle model of centerline + Pure Pursuit + obstacle memory) and
`runtime_nuevo.py`, so controller logic can be tuned without track time. `0a2c5d2`.
→ [README iteration log v2.1](README.md#53-iteration-log).

### 2026-08-12 — Obstacle detection hardening
`vision.py` shape filtering — area, solidity, aspect ratio — so the mat's coloured lines
are not read as pillars. Several same-day passes.

### 2026-08-13 — BEV calibration 4 → 9 points
RANSAC fit over a 3×3 grid of physical floor markers; a 4-point fit is exact and cannot
reject a mis-click or check reprojection error. `daf1e03` (a batch of `test`/`Revert`
commits precede it — the failed attempts). → [README iteration log v2.2](README.md#53-iteration-log).

### 2026-08-15 — "line memory" tried and reverted
`89f9d51` → `270b783` same day. Kept in the log as a rejected approach.

### 2026-08-17 → 08-19 — Orange / blue ground-line tracking
Row-by-row tracking of the mat's corner lines in the BEV — a turn trigger and a
"my straight vs. the next one" boundary for obstacles. `d3a611e` · `8edc1b8`.
**2026-08-18 was a heavy revert day** — a batch of centerline and `.ino` experiments all
backed out (`663d45b` … `42b397a`); the net keeper was `770c9a3` (RemoverLines).
`d592798` (WallDistance) starts feeding ultrasonic wall distance toward steering.
→ [README iteration log v2.3](README.md#53-iteration-log).

---

## Phase 5 — Wall-aware steering; Open Challenge validated (2026-08-20 → 08-28)

### 2026-08-20 → 08-21 — `ParedCenterline` merged
Centerline biased by ultrasonic wall distance (it drifted toward the outer wall on wide
corners without it); V2 protocol fixes; BetterSteering / BetterDodge passes; ghost-object
handling started. `f5066e1` · `24b2ec7`.
→ [README iteration log v2.4](README.md#53-iteration-log).

### 2026-08-24 — Ghost obstacle after a turn
Cans left in memory after a turn kept a phantom keep-out. First fix reverted, v2 shipped.
`a41ac0e` → `3c96abf`. `333b0e1` ("FreshStart: GirandoStep1") begins a rebuild of the
turn logic.

### 2026-08-25 → 08-27 — Line-classification & centerline tuning stretch
Long run of small commits and reverts on orange/blue line classification and centerline
stability; segmented-obstacle and interior-turn prototypes (`510a89a`, `b55e317`);
turning-detection v2. `fb81fe6` ("back2Basics", 08-27) resets the branch after the
centerline experiments diverged.

### 2026-08-27 — Obstacle-pass pulse fixed; earlier dodge
`ff9c83b` — the `pasado` "obstacle physically cleared" pulse was never firing.
`68aab07` — earlier/stronger dodge and earlier RECUPERANDO. `ab574ab` — rolling-memory
`ds_px` brake on hard turns. `57d3218` — lateral rebase: enter RECUPERANDO when the can
crosses the axis, not when it passes behind.
→ [README iteration log v2.5](README.md#53-iteration-log).

### 2026-08-28 — `ERR-08`: Pi undervoltage → frame-rate rescale
~0.3 V drop on undersized power leads browned out the Pi under load. Re-fed in 22 AWG;
loop went **~7 → ~14 fps**. Half the per-frame knobs were then calibrated at the old rate
and firing twice as fast — every one re-scaled. `e4ca4f9` · `1a19cdb`.
→ [README ERR-08](README.md#err-08--raspberry-pi-undervoltage-from-undersized-power-wiring),
[iteration log v2.7](README.md#53-iteration-log).

### 2026-08-28 — Hot start + run recording
Pipeline runs disarmed during the button delay; the ESP32 is gated on the first real V2
line so the car never rolls on the fallback PID; MJPG `.avi` HUD capture from the moment
the button is pressed. `3245c1c` · `2355caf` · `f257371`.
→ [README iteration log v2.6](README.md#53-iteration-log).

### 2026-08-28 — `ERR-07`: RECUPERANDO anchor drifts (experiments)
The geometric dead-reckoning anchor for the recovery trigger drifted 200–400 mm in
1–2 s and fired early or late; `SPEED_SCALE` at 1.0 / 0.35 / 0.60 all wrong somewhere.
`f24c547` · `25d0565` and their reverts. Resolved the next day.
→ [README ERR-07](README.md#err-07--recuperando-trigger-tied-to-assumed-linear-speed).

### 2026-08-28 — **M8: Open Challenge validated**
10 complete autonomous runs from varied start positions and field configurations, track
direction latched by the car, no wall contact, correct finish, ~12 s per run at 60 %
motor. Focus moves to the Obstacle Challenge.
→ [README MIL-01](README.md#mil-01--open-challenge-full-autonomous-run).
**Evidence still to log:** per-run video links, commit SHA per run, CW/CCW split,
battery voltage before/after.

---

## Phase 6 — Obstacle-round root causes (2026-08-29)

### 2026-08-29 — `ERR-07` fixed: measured-state RECUPERANDO trigger
Anchor retired. New trigger reads state that is already measured — centerline avoidance
weight (ARM), the memory's own "is a can still in the way" test (CLEAR), and a heading
snapshot (SKEW ≥ 25°). A gentle dodge that straightens itself never stops for a recovery.
`52549c8`, then `ab637aa` · `ef40152` · `5eee517` · `0306cfd` · `98da50a` tuning.
→ [README iteration log v2.9](README.md#53-iteration-log).

### 2026-08-29 — `ERR-06` fixed: pivot-trap
Near a can the steer term hit ±0.9 (≈ full lock) so the car pivoted in place instead of
arcing; the can's `y` never advanced, so RECUPERANDO never armed. Fixes: `LOOKAHEAD_MIN_PX`
60 → 78; adaptive look-ahead and steer-gain re-keyed on the **longitudinal** gap;
`forget_color_obstacles()` on a confirmed pass so the centerline un-bends. `1daf563`.
**Confirmed clean at session orillas 417** — both cans cleared, all 12 turns.
→ [README ERR-06](README.md#err-06--the-car-pivoted-in-place-instead-of-arcing),
[iteration log v2.8](README.md#53-iteration-log).

### 2026-08-29 — Orange-line direction, fast verdict
Slope evaluated from the first frame; armed-debounce for a green can seen just after a
turn. `a9acdde` · `13b163b`.

---

## Phase 7 — Hardening, segmented turns, documentation (2026-08-31 → 09-06)

### 2026-08-31 — Exterior cone at the corner mouth
A can right at the corner: drive straight past it, *then* turn, so the blind arc can't
sweep into it. `4e5ca40`. → [README iteration log v2.11](README.md#53-iteration-log).

### 2026-08-31 — Turn direction inferred during the run
`TurnDirectionTracker` — direction latched from the orange corner-line slope while
running, not pre-set at check-in. `3a6735e` · `a72a751` · `e641817`
(`LINE_FIT_MAX_SLOPE_DEG` 45 → 72, one turn sense wasn't fitting).
→ [README iteration log v2.10](README.md#53-iteration-log).

### 2026-08-31 — Camera-safe service restart
CI and ops use `stop → sleep 4 → start`; `systemctl restart` doesn't release the CSI
device and the camera wedges. `9aff6c9`.
→ [README iteration log v2.12](README.md#53-iteration-log).

### 2026-08 → 09 — **branch** work (`Workin`, `SectionTurning`) — not on `main`
- **Segmented obstacle turns** `CRUCERO → MANIOBRA`: cruise to a set front-sensor
  distance, then a forward arc or a reverse pivot chosen from the outer-wall distance;
  a mandatory motor-coast phase before every direction reversal after **`ERR-04`** (a
  reversal with no coast destroyed a TB6612 and an N20). → README iteration log v3.0,
  [ERR-04](README.md#err-04--tb6612-and-motor-destroyed-by-a-reversal-with-no-coast-delay).
- **Mid-turn cone detector** (`mid_turn.py`) — Phase 1, logging only (`[MTURN]`).
  → README iteration log v3.1.
- **Open round on pure wall + gyro PID** — Pi steer ignored; per-round `AngGiro` /
  `MOTOR_MAX`; `giroArmado` corridor-arm; front-wall approach slow-down; `TERMINANDO`
  return-to-start finish. → README iteration log v3.2, `ERR-05`.

### 2026-09-01 → 09-06 — Documentation pass
README expanded to the current structure (architecture, V2 spec, ERR log, iteration log,
risk table, milestones); v-photos; wiring diagrams + PCB render; 3D models; Open Challenge
video and YouTube link; milestone journey.
`3955cf3` · `5eee9a2` · `a4379be` · `0bb3fd1` · `baaa2da` · `eca476b`.

---

## Phase 8 — National final (2026-09-07 → 09-19)

### 2026-09-07 → 09-17 — Pre-final hardening (summary)
The work between the documentation pass and the final is listed row by row in the
[README iteration log](README.md#53-iteration-log) (v3.3 → v3.9):
- Gyro heading-hold by default on clean straights; run 700 was the first clean 12-corner Obstacle run.
- Start from the parking lot (`INICIO`).
- Floor-referenced color correction.
- Camera check before arming.
- Obstacle-memory merge guard.
- Red hue range for the new venue.
- Parallel parking: perfect parks in runs 1025, 1052 and 1064. Run 1064 was a full clean Obstacle round including the park.

### 2026-09-18 → 09-19 — **M14: 1st place, Mexico national final**
Last changes before the rounds were a color calibration for the venue lighting and
firmware tuning (`fc2bc3e`, `7c3db40`, `e18ff45`). The code that ran was committed as
`d5cc66d` ("WRO National") and becomes release **`v1.0-nacional`**
([releases](docs/releases.md)). Documentation score: 26/30.

---

## Phase 9 — After the final: check, diagnose, choose the v2 components (2026-09-21 → 09-27)

### 2026-09-21 → 09-22 — Is the car still the same?
First week back: test runs to confirm the car behaves as at the final, before changing anything. They turned up two problems the final had hidden:
- **Strong light, run 1190:** the orange tape was read as red and a pale patch of floor as green. Fixed with two lighting-independent tests per blob (`RED_GR_MAX`, `GREEN_S_MIN_MED`). Replayed over 6 recorded runs: red detections in 1190 went 34 → 19 and green 164 → 65; every rejected detection was checked by eye and was false. → [ERR-17](docs/engineering-log.md#err-17--strong-light-tape-read-as-red-pale-floor-read-as-green).
- **Run 1188, corner 4:** the forward/reverse corner maneuver flipped at the last moment, because the outer-wall distance sat right on its 28 cm threshold, and the arc jammed. Probably the same failure we saw at the final. Fixed with hysteresis and one shared decision. → [ERR-22](docs/engineering-log.md#err-22--the-corner-maneuver-changed-its-mind-at-the-last-moment).

Both fixes are in `96145ba`.

- **Bird's-eye calibration re-checked** with 9 measured floor marks. The calibration we raced with compresses depth by ~2×. A new calibration (9 px error) is saved aside; the old one stays for racing until all the pixel-based settings are moved to millimeters. A refactor of the perspective transform was tried and reverted the same day (`f30328f` → `b2d91d6`).

### 2026-09-21 — Where does the time go? (Raspberry Pi 4 profiling)
Measured on the car with the real race code:
- The main Python thread used **97% of one core** and the loop ran at **14–18 fps**, depending on the scene.
- Camera capture was only ~5 ms; color detection ~20 ms; bird's-eye view + centerline ~45 ms.
- Building the debug overlay only on the frames that get recorded gained **+8.3%** (A/B test on the car: 16.7 → 18.1 fps).
- With the remote-view client connected, the Pi reached **84 °C** and throttled ([ERR-27](docs/engineering-log.md#err-27--the-remote-desktop-client-overheated-the-pi-4)).

Conclusion: a faster capture method would gain at most 5–10%. The real limit is the CPU and its temperature. → decision to move to a **Raspberry Pi 5** with an Active Cooler.

### 2026-09-21 → 09-24 — What to improve, and with which parts
We reviewed the logged failures by root cause. Most traced back to the car not knowing its own state well enough:
- Speed was open-loop, so the behavior changed with battery charge ([ERR-11](docs/engineering-log.md#err-11--a-fresh-battery-over-rotates-the-dodges)).
- The heading came from gyro-rate integration only ([ERR-23](docs/engineering-log.md#err-23--systematic-heading-offset-after-every-corner)).
- The front ultrasonic produced phantom echoes ([ERR-19](docs/engineering-log.md#err-19--phantom-echoes-from-the-front-ultrasonic)).

We also read the public repositories of other teams: the 2026 Mexican 30/30 documentation and the top teams of the 2025 World final. That gave us real data on distance sensors against the black wall:
- Multi-zone ToF sensors and the VL53L1X both reach ~80–100 cm.
- A low-cost LiDAR refreshed too slowly for our speed.
- ToF sensors mounted low hit the floor.

**Decisions:**

| Need | Chosen | Instead of | Why |
|---|---|---|---|
| Compute and heat | Raspberry Pi 5 16 GB + Active Cooler + M.2 HAT+ | More optimization on the Pi 4 | The profiling above |
| Near-field distance, rear sensing | 4 × VL53L1X, keeping the ultrasonics | LiDAR, multi-zone ToF | Simple driver, enough range for a near-field sensor, and teams that used it documented it well. The ultrasonics stay because the two types fail differently against the black wall |
| Heading | BNO085 (on-chip fusion) | MPU-6050 integration | 6.5% heading loss per run, −7.5° bias per corner |
| Speed and distance | Pololu 50:1 motor with encoder | Open-loop N20 | Battery-voltage dependence; the rules' reference build suggests an encoder |
| Clean power for the Pi | A second Mini560 only for the Pi | One shared regulator | Servo current spikes must not reach the Pi |

**All components were ordered this week.**

### 2026-09-26 — Firmware cleanup
One parking-mode switch (`PARK_MODO`: none / nose-in / parallel) replaces three booleans that had to be changed together; unused settings removed. `cdf6251`.

---

## Phase 10 — Components arrive; new mechanics; digital twin (2026-09-28 → 10-04)

### 2026-09-28 → 10-04 — Bench tests of the new components
The components arrived, and each one was tested alone before integration. One sketch per question:

| Sketch | Question it answers |
|---|---|
| [`TofId`](src/ESP32/TofId/TofId.ino) | Is this sensor an L0X or an L1X? It reads the model register directly, with no library. |
| `TofTest1`, `TofTest1_L1X` | Does one sensor range on the bus? |
| [`TofTest4`](src/ESP32/TofTest4/TofTest4.ino) | Can all four share one I²C bus? Each one is woken up with its XSHUT line and given its own address (0x30–0x33). |
| `BnoTest`, [`BnoRvcTest`](src/ESP32/BnoRvcTest/BnoRvcTest.ino) | BNO085 over I²C vs UART-RVC. RVC chosen: one wire, 100 Hz, checksum, no library, and it stays off the ToF bus. |
| [`TofBnoTest`](src/ESP32/TofBnoTest/TofBnoTest.ino) | All four ToF plus the BNO085 at the same time. It reports rates (ToF ~20 Hz each, BNO ~100 Hz), lost packets and ToF error codes. |
| `ServoTest` | The servo's real usable range for the new steering |

### 2026-09-28 → 10-04 — v2 mechanical design
Full redesign of the chassis to make the car shorter, around the new parts ([README §2.6](README.md#26-v2-chassis--shorter-car-pi-on-top)):
- The motor turns parallel to the rear axle, driving the differential with spur gears (module 1, 15T/30T, same 2:1 as the old bevel pair). Involute profiles generated as DXF by our own script.
- The battery moves to the center, crosswise, in a side-loading tunnel where the Raspberry Pi used to be.
- The Raspberry Pi 5 goes on top, open to the air for its fan.
- Overall length goes from ≈24 cm (including the extension added to leave the parking lot) to ≈17 cm (168.7 mm in CAD). Wheelbase ≈147 → ≈113 mm. Camera tilt ≈20° down.

We also started reworking the steering for the shorter car (finished in Phase 11) and worked out how to fit everything.

### 2026-10-02 → 10-06 — Digital twin (Jesse) — **branch** `digital-twin`, not on `main`
A **software-in-the-loop simulator** of the whole car. It runs the real Pi code (`runtime_nuevo.py`) and the real ESP32 firmware, compiled for the PC, against a simulated field with randomized pillar layouts (one "seed" per layout). Each run produces the same logs as the real car. Highlights, with the full record in the branch's `docs/twin_plan.md`:
- **First batch of 7 layouts:** 4 hit a green pillar 1–3 s after a right turn. One was traced frame by frame to a rule that released the "wait before turning" block too early when a green sat in the first column of the next straight.
- **v2 hardware preset (`hw_nuevo`):** encoder, 4 ToF, BNO085 model, the new dimensions, and the Raspberry Pi 5. Frame-based settings were made independent of the frame rate (`df84b28`, `25de149`).
- **Parallel parking planned with the map of the field:** 91/100 successful parks over a harness of start positions, and 98/100 when grazing the outer wall is allowed (`58a1338`, `87532bb`).
- **Determinism checks** (the same seed gives the same run) and a sensor-noise ensemble, so a change can be compared across many layouts instead of one track run.

---

## Phase 11 — Raspberry Pi 5 bring-up, steering finalized, PCB started (2026-10-05 → 10-07)

### 2026-10-06 — Raspberry Pi 5 set up for headless work
- SSH with key-only login over Tailscale.
- Logs that survive reboots.
- The repository and a Python environment that reuses the system OpenCV, which has GStreamer.
- `rpi-lgpio` in place of `RPi.GPIO`, which does not support the Pi 5.
- The ESP32 link moved to `/dev/ttyAMA0` (on the Pi 5, `/dev/serial0` is the debug connector).
- Boot time 53 s → 13 s after the first boot.

### 2026-10-06 — Raspberry Pi 5 benchmark
The unmodified race runtime, replaying recorded run 1190 as the camera input at 30 fps, ran at **40–41.5 fps** with the Pi at 46 → 52 °C and no throttling. The Pi 4 managed ~15.5 fps on the same run.

Found on the way: the main loop doesn't wait for a new camera frame, so at 40 fps it re-processes about one frame in four. The settings counted in frames would then run ~3× faster in real time. Open item: cap the loop rate, or move those settings to seconds (the twin branch already did the latter).

### 2026-10-06 → 10-07 — Camera bring-up on the Pi 5
- The camera wasn't detected automatically → driver loaded explicitly for port CAM1.
- The race pipeline failed with `not-negotiated` → fixed with `format=BGRx` (30 fps, ~2% CPU) — [ERR-28](docs/engineering-log.md#err-28--raspberry-pi-5-the-race-camera-pipeline-would-not-start).
- **Magenta ring at the frame edges** (corners R/G 1.31–1.40 on a white sheet). Root cause: the factory lens-shading table, made for the stock lens. We calibrated a new table for our lens from 5 photos of a white sheet with the official Raspberry Pi tuning tool, then symmetrized its brightness part to remove the uneven lighting of the sheet. Result: R/G and B/G = 1.00 at the center and all corners. The table is shipped in the repository with the procedure, to repeat it at the venue — [ERR-29](docs/engineering-log.md#err-29--raspberry-pi-5-magenta-ring-at-the-frame-edges), [`camera_tuning/`](src/RASPI/cam/camera_tuning/README.md).
- A browser-based live view and color-calibration tool (`cam_web.py`), because the Pi 4's remote-desktop client doesn't work on the Pi 5's desktop.

### 2026-10-06 — Steering geometry finalized
- **Diagnosis:** we simulated the linkage in Python with the CAD dimensions (model within ~1° of the CAD). The old geometry was **anti-Ackermann**: 39.5° inner wheel against 42.8° outer.
- **Fix, reprinting only the rack, the two tie rods and the pinion:** rack joints 43 → 47 mm, tie rods 18.13 mm, pinion 14 → 19 teeth (servo moved 2.5 mm).
- **Result in CAD:** **53.1° inner / 37.0° outer, ~106% Ackermann**. Turning radius ~208 → ~115 mm together with the shorter wheelbase ([README §2.4](README.md#24-steering--rack-and-pinion-with-ackermann-geometry)).

### 2026-10-05 → 10-07 — Mechanical design finished; tests with the new parts; PCB started
- Mechanical v2 design completed, around the final steering.
- Tests with the new components on the car.
- Start of the **two-floor PCB**: a power floor with both regulators, the motor driver, switch and fuse; and a logic floor with the ESP32 and the connectors for 3 ultrasonics, 4 ToF, BNO085 and servo ([README §3.3](README.md#v2-pcb--two-floor-board-in-design)).

### 2026-10-06 → 10-07 — Documentation for the international final
- The `parking` branch merged into `main` (`844195e`, `2dd11cf`). The README judged at the final is kept as the base, with v2 added on top.
- New: [releases](docs/releases.md), [test record](docs/testing.md), [engineering log](docs/engineering-log.md) (ERR-10 onward), §5.0 design constraints, the v2 power budget, sensor placement against the field geometry, and the BNO085 + ToF sections.

---

## Open items (as of 2026-10-07)

| Item | Milestone | State |
|---|---|---|
| Frame rate on the Pi 5: cap the loop or move per-frame settings to seconds | M15 | Open; done on the twin branch, not yet on `main` |
| Re-check the red/green/orange/magenta thresholds under the new camera calibration | M15 | Open |
| Encoder, BNO085 and ToF in the race firmware (ToF and BNO log-only first) | M16 | Bench-tested; twin model on branch |
| BNO085 heading with the motor running at standstill (magnetometer check) | M16 | Pending |
| Two-floor PCB designed, fabricated, wired; v2 wiring diagram | M16 | In design |
| v2 CAD/STL and renders into `models/`; measure the printed car (size, weight, turning radius) | M16 | Pending |
| Merge the `digital-twin` work into `main` | M16 | On branch |
| Validation matrix for v2: both directions, 3 consecutive clean runs | M16 | Not started |
| Tag `v1.0-nacional`; tag `v2.0-internacional` before the event | — | Pending |
| Documentation deadline | — | 2026-11-24 |

---

## How this journal is maintained

- New entry at the bottom of the current phase, dated, with the **why** and the **measured
  result** — not just what changed.
- When a change lands on `main`, add the commit short-hash. Branch work is labelled
  **branch** until merged.
- [README §5.3](README.md#53-iteration-log) stays the thematic summary; this file is the
  timeline. Keep them consistent when either changes.

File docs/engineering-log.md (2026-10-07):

# Engineering Log — FoxRobotics, WRO 2026 Future Engineers

This log continues the failure log of the [README §5.5](../README.md#55-failure--incident-log) (ERR-01 to ERR-09, up to 2026-09-06) and records the decisions, failures and milestones that changed the robot after that. Every entry points to evidence: a recorded run (`orillasNNN` = run number NNN, a video plus the Pi's journal), a commit, or a measurement. We add entries; we do not rewrite them. When a later change replaces an entry, we mark it *Superseded* and keep it.

**Status legend**

| Status | Meaning |
|---|---|
| Validated | The fix was tested on the track and the acceptance check passed |
| Validated (replay) | Validated by replaying recorded runs through the new code, not yet on the track |
| Mitigated | The symptom is controlled, but the root cause is still there |
| Under investigation | The cause is known or suspected; the fix is not done |
| Rejected | Tried and removed, with the reason |

**How we find problems.** Every run records the camera and bird's-eye view to `videos_orillas/orillasNNN.avi`, and the Pi logs every message sent to the ESP32 and every ACK it gets back (`journalctl`). [`scripts/reporte_run.py`](../scripts/reporte_run.py) turns the journal into a per-corner report: state changes, heading, distances and maneuver choices. Most entries below were diagnosed by matching the video frame to the log line. See [testing.md](testing.md).

---

## 1. Decision log — "we chose X instead of Y because…"

| ID | Decision | Alternatives considered | Why (data) | Status |
|---|---|---|---|---|
| DEC-01 | Split the work: vision on a Raspberry Pi, real-time control on an ESP32 | Everything on one board | On the Pi, one 640×480 HSV pass takes 8–15 ms. Running it next to servo PWM and ultrasonic timing makes the control loop jittery. The ESP32 keeps driving on the gyro if the Pi stalls for > 800 ms. | Validated |
| DEC-02 | HC-SR04 ultrasonics for walls (v1) | VL53L0X ToF | The VL53L0X returned out-of-range on the black walls at 300 mm in most readings. Revisited in DEC-12. | Superseded by DEC-12 |
| DEC-03 | Pure Pursuit on a bird's-eye view | PID on the sign's x-offset in the camera image | In the raw image, pixel offset ≠ distance (a near and a far sign need different gains). In the bird's-eye view 1 px ≈ 2 mm, and Pure Pursuit uses the car's real geometry, so one controller handles straights, dodges and corner exits. | Validated |
| DEC-04 | On a clean straight, steer with the **gyro**. Vision steers only while dodging. | Vision steers all the time | With vision always steering, each small dodge left the chassis 20–30° crooked and the car drifted into a wall (runs 679–690). After the change, run 700 was the first clean 12-corner run. | Validated (run 700) |
| DEC-05 | Obstacle Challenge corners: **stop, then forward arc or reverse pivot**, chosen by the distance to the outer wall | Continuous turn (as in the Open Challenge) | The continuous turn kept hitting or skipping the sign at the mouth of the next straight. Two weeks before the national final we chose points over time: the score ranks first, time only breaks ties. | Validated (national final) |
| DEC-06 | "Sign passed" trigger from **measured state**: real dodge happened + nothing ahead in memory + chassis turned ≥ 15° | Dead-reckoned sign position from where it was first seen | We tried the dead-reckoned version four times (angle → geometric → geometric v2 → speed-scale tuning). Each was overfit to one recorded run. The geometric one crashed on the track (`d906e97`, reverted in `2a92e0d`). | Validated |
| DEC-07 | `RECUPERANDO` cannot be interrupted by a newly seen sign | Let a new sign take over immediately | While the chassis is still turned, the "new" sign is usually the one just passed, or one from the next straight. Interrupting sent the car towards it. | Validated |
| DEC-08 | Venue robustness through **floor-referenced color correction plus ratio tests** (blue/red, green/red, saturation) | Widen the HSV ranges, or raise camera gain | Hue near red wraps around and shifts tens of units with lighting, while the white floor barely changes. Ratios between channels stay stable under different lighting. Widening the hue range made the pink lot walls and the orange tape read as red (ERR-13, -04, -06). | Validated (replay over 6 runs) |
| DEC-09 | Keep the Pi 4 at ~14 fps and rescale every per-frame constant | Process every 2nd frame at ~7 fps | Lower latency gave smoother dodges. Constants written as "N frames" doubled their effect at 2× fps; we rescaled 8 of them so they keep the same meaning in seconds (`03df4ae`). | Validated |
| DEC-10 | Upgrade to a **Raspberry Pi 5 (16 GB) + Active Cooler** | Optimize the Pi 4 further, or move to Picamera2 capture | Profiling showed capture was only ~5 ms of a ~65–77 ms frame; vision and path planning were the cost, and the Pi 4 throttled at 84 °C. A faster capture method would gain ≤ 5–10%. The Pi 5 runs the same pipeline at 40–41.5 fps at 52 °C (replayed run 1190). | Under test (port in progress) |
| DEC-11 | Fix the steering: rack joints 43 → 47 mm, tie rods 18.13 mm, pinion 14 → 19 teeth | New knuckles with a shorter arm; move the rack back 6 mm | Linkage simulation matched the CAD within ~1°. Moving the rack meant reprinting the chassis, and a shorter arm risked the linkage locking up. The bigger pinion + new spacing gives 53.1° / 37.0° (~106% Ackermann) by reprinting only the rack, two linkages and the pinion. | Validated in CAD; track test pending |
| DEC-12 | Add 4 × VL53L1X ToF as **near-field** sensors, keep the HC-SR04 | LiDAR; multi-zone VL53L8CX; ultrasonics only | The front ultrasonic produced phantom echoes (ERR-19). Teams that tested ToF on the WRO black wall report ~80–100 cm usable range, with L1X ≈ L8CX. The L8CX had initialization problems for another team. The low-cost LiDAR another team tested refreshed only ~5 scans/s, too slow at our speed. | Under test (bench) |
| DEC-13 | **Don't rely on a magnetometer heading** without testing it on the car. No optical-flow sensor. | — | Magnetometer: the motor and the LiPo sit a few centimeters away and their fields can pull it. The BNO085 we chose for v2 does include one, so its heading is checked with the motor running at standstill before it gets control. If it drifts, we use its gyro + accelerometer output instead. Optical flow: the mat is mostly white with little texture to track. | Under test (BNO085); optical flow rejected |

---

## 2. Failure and incident log

### Power

#### ERR-08 — Pi 4 undervoltage halved the frame rate
Logged in the README: [ERR-08](../README.md#err-08--raspberry-pi-undervoltage-from-undersized-power-wiring).

#### ERR-10 — Power cut right after `git pull` left files empty
- **Observed:** 2026-09-12 and 2026-09-15. After an update, the runtime service restarted every 2 s without running anything.
- **Cause:** The battery was unplugged seconds after `git pull`. The files had not yet been written to the SD card, so they were left at 0 bytes. On 09-15 some of git's internal object files were empty too.
- **Fix:** Restored the empty files from the repository. Added a rule to the update procedure: `git pull && sync` before unplugging.
- **Status:** Mitigated (procedure).

#### ERR-11 — A fresh battery over-rotates the dodges
- **Observed:** runs 842 (bad) vs 834 (good), 2026-09-10/11, same code.
- **Data:** Heading swing in red dodges was −58…−82° in 842 vs −33…−54° in 834. The corner pivot, which runs at a fixed PWM with no Pi input, rotated 2.62°/frame vs 2.23–2.28: ~17% more motor power. The car left corners ~5 cm closer to the outer wall, and every following dodge started from the wrong place.
- **Good window:** 11.70–12.15 V on the 3S pack.
- **Mitigation:** Run inside the window (discharge a fresh pack first).
- **Fix in progress (v2):** a Pololu 50:1 motor with encoder is now mounted. The next step is a closed speed loop on the ESP32, so the motor delivers the same speed at any charge level. A battery-voltage reading on an ESP32 analog pin remains a cheap backup.
- **Status:** Mitigated (procedure).

### Vision

#### ERR-12 — Camera blackout mid-run
- **Observed:** run 860. The car never turned and crashed. Run 859 had 8% black frames, run 861 had 2%.
- **Diagnosis:** We decoded every recorded bird's-eye frame and measured the 99th-percentile brightness. In run 860, 48% of frames were blind, including **19 s in a row** of full-frame color noise from the camera interface. The Pi kept processing frames; the camera was what failed. File size can't detect it: the noise frames weigh the same as good ones.
- **Fix:** Before arming, the runtime requires real frames (99th-percentile brightness ≥ 60). It reopens the camera if it sees 15 black frames in a row or no new frame (`CAM_CHECK_*`, "Feat: Camera check up", 2026-09-14). The status LED stays off until the camera passes, so a bad camera is caught before the start, not during the run. Commit `486cc4c`.
- **Status:** Mitigated. A blackout *during* a run is still not handled.

#### ERR-13 — Pink parking-lot wall detected as a red sign
- **Observed:** run 808, 2026-09-09, on the straights next to the parking lot. The car dodged a sign that wasn't there.
- **Diagnosis:** The dark part of the lot wall reads hue ≈ 3, inside the red range. The fixed camera white balance (blue gain 1.5×) pushes magenta towards red. A real sign is a blob that grows as the car approaches; the wall was "passed" straight ahead, with almost no turn.
- **Fix:** Added a blue/red ratio test on each blob (`RED_BR_MAX = 0.42`): real red signs measure 0.11–0.35, the pink wall 0.45–0.60. A ratio doesn't shift with lighting color the way hue does. Commit `e3784a8` (2026-09-16).
- **Status:** Validated.

#### ERR-14 — At a new venue, red signs were not detected at all
- **Observed:** run 1013, 2026-09-16. The car did not dodge the red sign.
- **Diagnosis:** Under that lighting the red sign measured hue 169–178. Our range covered ≤ 5 and ≥ 177, so a large sign 20 cm away produced zero detections. Old runs showed the sign at 169–171 too: we had always caught only its edge, which is why red was always detected late.
- **Fix:** Red range widened to 168–179, brightness limit raised. The pink-wall protection moved from the hue limit to the ratio test of ERR-13 (`e3784a8`).
- **Status:** Validated. This led to `calibra_luz.py`, a venue calibration tool for the practice time.

#### ERR-15 — In a darker room the orange line was read as red
- **Observed:** run 900. Orange line not detected; red signs only detected when close.
- **Diagnosis:** Floor brightness 212 → 184. The tape's hue fell from 9 to 4, into the red range (orange starts at 7). Only 17% of tape pixels still passed as orange.
- **Fix:** `color_corr.py` rescales the image channels so the white floor matches a reference color. On the same recorded run: tape detected as orange 17% → 44%, tape detected as red 3% → 0%. Cost ~1.9 ms/frame. The brightness gain is capped, so real signs don't get pushed out of their range. Commit `7bd353f`.
- **Status:** Validated (replay), then raced.

#### ERR-16 — False orange line in the middle of a straight
- **Observed:** runs 818 and 820. The car stopped dodging a green sign halfway, because the "line" made the sign look like it belonged to the next straight.
- **Causes:** (1) A stray pixel in the same column as the real line made it look 170 px closer. (2) Brown marks drawn on the test floor have the same hue as the tape but much lower saturation: floor marks have S 86–112, real tape S 140–198.
- **Fix:** The line must be a run of ≥ 3 neighboring columns, and must contain ≥ 8 strongly saturated "core" pixels (`LINE_CORE_HSV`). Replay of run 818: the false window disappears, and all 13 real corners still detect their line before the turn. Commit `283addd`.
- **Status:** Validated.

#### ERR-17 — Strong light: tape read as red, pale floor read as green
- **Observed:** run 1190, 2026-09-22 (after the national final).
- **Data:** Orange tape matched red by hue but had green/red = 0.38–0.46; a real red sign has 0.05–0.13. Washed-out floor matched green by hue but had saturation 37–44; a real green sign has 120–160.
- **Fix:** Two more lighting-independent tests per blob: `RED_GR_MAX = 0.28` and `GREEN_S_MIN_MED = 70`. Replay: run 1190 red detections 34 → 19 and green 164 → 65. Every rejected crop was checked by eye and was false. Runs 1005, 1064 and 1150 were unchanged. Commit `96145ba`.
- **Status:** Validated (replay over 6 runs).

#### ERR-18 — Camera tilted up caused over-steering
- **Observed:** 2026-09-09, 4 runs. The car turned too hard and too early on one red sign, sometimes pushing itself into the inner wall.
- **Cause:** The camera mount had tilted ~8° up. That inflated lateral distances in the bird's-eye view, so Pure Pursuit asked for more steering than needed and saturated (+41°).
- **Fix:** Re-leveled the camera. Peak steering command 0.68 → 0.35, no saturation, and the wall-protection override never fired again.
- **Lesson:** The bird's-eye calibration is only valid for one camera angle. The v2 camera mount must be rigid, and the calibration is re-checked after any impact.
- **Status:** Validated.

### Sensors

#### ERR-19 — Phantom echoes from the front ultrasonic
- **Observed:** run 1047 (2026-09-16) and 2026-09-17, Open Challenge. The car slowed down in the middle of straights.
- **Data:** The front distance fell under 90 cm in ~20% of straight-line frames, with impossible jumps such as 199 → 65 → 179 cm. On 09-17 the phantoms appeared almost only while the car ran 24–28 cm from the side wall.
- **Tried:** Firing one sonar per loop and shutting off the outer sonar. The run got worse, and we reverted it completely.
- **Hypothesis:** The wide ultrasonic cone grazes the side wall.
- **Next:** Tilt or raise the front sonar, and add the VL53L1X (DEC-12).
- **Status:** Under investigation.

### Navigation

#### ERR-20 — Drift towards a wall after small dodges
- **Observed:** runs 679–690 (2026-09-05).
- **Cause:** Small dodges never turned the car enough to trigger the "passed" event, so the chassis stayed 20–30° crooked and the following wall control could not recover.
- **Fix:** DEC-04 (gyro heading-hold by default). Also added a proportional wall-protection override (`wallPanic`, below 18 cm), and limited the corner re-referencing of the heading target so it cannot chase a runaway angle.
- **Status:** Validated (run 700 = first clean 12-corner run).

#### ERR-21 — Two red signs on both sides of a corner merged into one
- **Observed:** run 954, 2026-09-15.
- **Cause:** While dodging a red sign, the red of the next straight appeared 69 px from where the memory had moved the old one. They were merged, and the new sign inherited "ours". The car dodged it at full lock and hit the wall.
- **Fix:** A remembered sign cannot "reappear" more than 40 px to the side **and** more than 15 px further ahead than it could physically be. This check can only prevent merges, never create them. Commit `8bfe4d0`.
- **Validation:** Replayed 16 runs (37,774 frames) through the memory with and without the fix. Only 8 frames differ: the fix itself in run 954, and one 1-frame shift in run 933.
- **Status:** Validated (replay).
- **Found on the way:** The memory rotates the map with the wrong sign: 10.9 px/frame error vs 3.9 with the right sign. It is not fixed yet, because three other components were tuned around it.

#### ERR-22 — The corner maneuver changed its mind at the last moment
- **Observed:** run 1188, corner 4 (2026-09-22). Probably the same failure seen at the national final.
- **Cause:** The distance to the outer wall sat at 27–29 cm, exactly on the 28 cm threshold between "forward arc" and "reverse pivot". The approach decided *reverse*, the final check read 27 and chose *forward* at 15 cm from the wall, and the arc jammed.
- **Fix:** Threshold 20 cm with ±6 cm hysteresis. One shared decision for the approach and the maneuver. A forward arc with less than 35 cm of room ahead is forced to reverse. The ACK now reports `hug=`. Commit `96145ba`.
- **Status:** In repository, not yet validated on the track.

#### ERR-23 — Systematic heading offset after every corner
- **Observed:** runs 853–856, 37 straights.
- **Data:** Right after each maneuver the heading was −7.5° ± 0.9°: a constant bias of 5° we add on purpose plus ~2.5° of under-rotation. That part can be calibrated. The drift that varies is built **inside** the straights, by the dodges.
- **Mitigation:** The parking sequence re-measures the heading against the wall (`PARK_TRIM_*`).
- **Proper fix:** An absolute heading reference from the walls, which is one of the goals of the side ToF sensors.
- **Status:** Mitigated.

#### ERR-24 — Green-then-red slalom: the red is grazed "sometimes"
- **Observed:** runs 843–845 (2026-09-11). Run 845 grazed the red in lap 2 and pushed it out of its area in lap 3. Runs 843 and 844 passed cleanly.
- **Data:** The difference is millimeters. When the green ends up on the "wrong" side of the car's line after the corner, the green dodge grows from 6–18° to 19–56°. Then the red is seen only 20 cm ahead and needs a 58–74° dodge.
- **Lever:** The red is already visible from the corner exit as a 500–850 px blob, but the detector ignores blobs under 1000 px.
- **Status:** Under investigation.

### Software process

#### ERR-25 — The geometric "sign passed" trigger crashed on the track
- **What happened:** On 2026-08-28 we computed the moment the sign is passed from where it was first seen plus dead reckoning. It worked in a synthetic simulation, then crashed on the track. We reverted it the same day (`d906e97` → `2a92e0d`).
- **Lesson:** Never replace a trusted behavior with one validated only in simulation. New behaviors are now first added in log-only mode next to the old one (`[RECUP]`, `[MTURN]` log lines), compared on recorded runs, and only then given control.
- **Status:** Rejected → replaced by DEC-06.

#### ERR-26 — Doubling the frame rate made the car "more aggressive"
- **Observed:** 2026-08-28, after ERR-08 doubled the fps.
- **Cause:** Constants counted in frames now acted twice as fast: steering slew, memory decay, line persistence, post-turn recovery, and the duration of the "passed" pulse.
- **Fix:** All rescaled to keep the same value in seconds (`03df4ae`).
- **Lesson:** This applies again on the Pi 5 (40 fps). See [testing.md](testing.md).
- **Status:** Validated, and open again for v2.

#### ERR-27 — The remote desktop client overheated the Pi 4
- **Observed:** 2026-09-21. The remote screen client used 55–60% of a CPU core, and the Pi reached 84 °C with its soft temperature limit active (`throttled=0xe0008`).
- **Effect:** 16.1–16.8 fps with the client connected vs 18.1 without.
- **Mitigation:** Disconnect it while tuning or measuring fps. Wireless must be off during official rounds anyway (rule 11.10).
- **Fix:** The Pi 5 with the Active Cooler.
- **Status:** Mitigated.

### Raspberry Pi 5 port

#### ERR-28 — Raspberry Pi 5: the race camera pipeline would not start
- **Observed:** 2026-10-06, first camera test on the Pi 5. The photo tool worked, but `vision.open_camera()` failed: `libcamerasrc: Internal data stream error`, `not-negotiated`.
- **Diagnosis:** We tested the pipeline piece by piece with `gst-launch`. Without an explicit pixel format, the camera source and the rest of the pipeline can't agree on one with the Pi 5's image processor (PiSP). With `format=NV12` it works at 20 fps, because the color conversion falls to the CPU. With `format=BGRx` it works at **30 fps using ~2% CPU**, because the image processor does the conversion.
- **Also found:** The automatic camera detection didn't recognize our module at all. A CSI camera is also only detected at boot (plugging it in with the Pi on does nothing). Loading the driver for both ports showed the sensor answering on CAM1 and nothing on CAM0.
- **Fix:** `format=BGRx` in `vision.py`; `camera_auto_detect=0` + `dtoverlay=imx219,cam1` in `/boot/firmware/config.txt`. The field of view is unchanged (same 1640×1232 sensor mode as the Pi 4), so the bird's-eye calibration still applies.
- **Status:** Resolved.

#### ERR-29 — Raspberry Pi 5: magenta ring at the frame edges
- **Observed:** 2026-10-07. With the Pi 4 gains (1.2 / 1.5), and even after re-balancing on a white sheet, the edges of the frame were strongly magenta. On a white sheet the corners measured R/G 1.31–1.40 and B/G 1.26–1.35, against ≈ 1.0 at the center.
- **Why it matters:** Magenta at the edges is close to the pink parking-lot walls and to the red pillars (see ERR-13).
- **Cause:** Lens shading. The image processor corrects each zone of the image with a lens-shading table (ALSC) made for the stock lens. For the red channel it *raises* the corners (×1.33 relative to the center), the opposite of what our wide-angle lens without an IR filter needs. Gains can't fix this, because they scale the whole image equally.
- **Fix:** We took 5 raw photos of an evenly lit white sheet at ~3700 K, and the official Raspberry Pi tuning tool (`rpi-ctt --alsc-only`) computed a new table into a copy of `imx219_noir.json`. The brightness part of the table came out asymmetric (top corners ×4.3, bottom ×2.0), because the sheet was darker at the top. Lens vignetting is symmetric, so we averaged that part with its mirror images. Result: ×2.93 at every corner, almost identical to the factory ×2.96, so the lens darkens the edges like the stock one and only their color is different. Then we re-balanced: gains `<1.10,1.51>`.
- **Result:** R/G and B/G = 1.00 ± 0.01 at the center **and** at all four corners. The tuning file and the full procedure, so we can repeat it at the venue, are in [`src/RASPI/cam/camera_tuning/`](../src/RASPI/cam/camera_tuning/README.md).
- **Status:** Resolved. The HSV thresholds still need checking on real pillars under the new image.

---

## 3. Milestones

These continue the milestone table of the [README §6.5](../README.md#65-milestones).

| README # | Date | Run | Result |
|---|---|---|---|
| M12 | 2026-09-05 | 700 | First clean 12-corner Obstacle Challenge run with stop-and-turn corners |
| M11 | 2026-09-16 | 1025 | First perfect parallel park; its constants became the reference set |
| — | 2026-09-16 | 1047 | Open Challenge 12/12 corners (with the phantom slow-downs of ERR-19) |
| M13 | September 2026 | 1064 | Full clean Obstacle Challenge: start from the lot, 12 corners, parallel park (heading error 0.9° at the end) |
| M14 | 2026-09-19 | — | **1st place, Mexico national final**, with release [`v1.0-nacional`](releases.md) |
| M15 | 2026-10-06 | 1190 (replay) | Unmodified pipeline at 40–41.5 fps on the Raspberry Pi 5 |

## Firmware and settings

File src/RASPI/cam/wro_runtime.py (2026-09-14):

import argparse
import os
import re
import sys
import threading
import time
from dataclasses import dataclass
from pathlib import Path
from queue import Empty, Full, Queue

import cv2
import numpy as np



REPO_ROOT = os.path.dirname(os.path.dirname(os.path.dirname(os.path.abspath(__file__))))
RASPI_CAM_DIR = os.path.dirname(os.path.abspath(__file__))
if RASPI_CAM_DIR not in sys.path:
	sys.path.append(RASPI_CAM_DIR)

from vision import Vision


WOOD_LOWER = np.array([5, 25, 40])
WOOD_UPPER = np.array([35, 180, 255])
OUTPUT_PATTERN = re.compile(r"^orillas(\d+)\.(?:mp4|avi)$")
CAM_FRAME_PATH = "/tmp/wro_cam_frame.jpg"


class ThreadedFrameGrabber:
	def __init__(self, cap):
		self.cap = cap
		self.lock = threading.Lock()
		self.frame = None
		# read() devuelve el ÚLTIMO frame para siempre, aunque la cámara deje de
		# mandar (cap.read() se cuelga 30 s por intento). frame_id/frame_t dicen
		# si de verdad llegan frames nuevos (ver chequeo de cámara de runtime_nuevo).
		self.frame_id = 0
		self.frame_t = 0.0
		self.stopped = False
		self.thread = threading.Thread(target=self._run, daemon=True)

	def start(self):
		self.thread.start()
		return self

	def _run(self):
		failures = 0
		print("[CAM] Hilo de captura iniciado", flush=True)
		while not self.stopped:
			ret, frame = self.cap.read()
			if not ret:
				failures += 1
				print(f"[CAM] cap.read() fallo #{failures}/100", flush=True)
				if failures >= 100:
					print("[CAM] Demasiados fallos, deteniendo hilo", flush=True)
					self.stopped = True
					break
				time.sleep(0.05)
				continue
			if failures > 0:
				print(f"[CAM] Frame recibido despues de {failures} fallos", flush=True)
			failures = 0
			with self.lock:
				self.frame = frame
				self.frame_id += 1
				self.frame_t = time.monotonic()
		print("[CAM] Hilo de captura terminado", flush=True)

	def read(self):
		with self.lock:
			if self.frame is None:
				return False, None
			return True, self.frame.copy()

	def freshness(self):
		"""(frame_id, segundos desde el último frame NUEVO). frame_id=0 = ninguno aún."""
		with self.lock:
			if self.frame_id == 0:
				return 0, float("inf")
			return self.frame_id, time.monotonic() - self.frame_t

	def stop(self):
		self.stopped = True
		if self.thread.is_alive():
			self.thread.join(timeout=1.0)


def create_writer(output_path: str, frame_width: int, frame_height: int, fps: float):
	# MJPG en .avi: cada frame es un JPEG independiente y el .avi escribe los
	# frames de forma progresiva -> si el proceso muere sin cerrar (congelado,
	# brownout, SIGKILL) el archivo QUEDA REPRODUCIBLE hasta donde alcanzó a
	# escribir. mp4v en .mp4 no: el índice (moov) se escribe solo en release()
	# y sin él ffmpeg/VLC no abren nada (se perdieron orillas37..373).
	fourcc = cv2.VideoWriter_fourcc(*"MJPG")
	return cv2.VideoWriter(output_path, fourcc, fps, (frame_width, frame_height))


class AsyncVideoWriter:
	def __init__(self, output_path: str, frame_width: int, frame_height: int, fps: float, max_queue_size: int = 8):
		self.writer = create_writer(output_path, frame_width, frame_height, fps)
		self.queue = Queue(maxsize=max_queue_size)
		self.stopped = False
		self.thread = threading.Thread(target=self._run, daemon=True)

	def start(self):
		self.thread.start()
		return self

	def _run(self):
		while not self.stopped or not self.queue.empty():
			try:
				frame = self.queue.get(timeout=0.05)
			except Empty:
				continue
			try:
				self.writer.write(frame)
			finally:
				self.queue.task_done()

	def write(self, frame):
		if self.stopped:
			return
		try:
			self.queue.put_nowait(frame)
		except Full:
			try:
				self.queue.get_nowait()
				self.queue.task_done()
			except Empty:
				pass
			try:
				self.queue.put_nowait(frame)
			except Full:
				pass

	def stop(self):
		self.stopped = True
		if self.thread.is_alive():
			self.thread.join(timeout=2.0)
		self.writer.release()


def next_output_path(directory: Path) -> Path:
	directory.mkdir(parents=True, exist_ok=True)

	highest_index = 0
	for candidate in directory.iterdir():
		match = OUTPUT_PATTERN.match(candidate.name)
		if match:
			highest_index = max(highest_index, int(match.group(1)))

	return directory / f"orillas{highest_index + 1}.avi"


def resolve_output_path(output_path: str | None) -> Path:
	if output_path:
		path = Path(output_path)
		if path.suffix.lower() in (".mp4", ".avi") and OUTPUT_PATTERN.match(path.name):
			return next_output_path(path.parent)
		if path.is_dir() or not path.suffix:
			return next_output_path(path)
		path.parent.mkdir(parents=True, exist_ok=True)
		return path
	return next_output_path(Path.cwd())


@dataclass
class Config:
	cam_index: int = 0
	serial_port: str = "/dev/ttyS0"
	baudrate: int = 115200
	protocol: str = "signed"
	show_window: bool = True
	process_every_n: int = 3
	threaded_capture: bool = True
	warmup_frames: int = 40

	red_target_px: int = 140
	green_target_px: int = 500
	neutral_x: int = 700

	pid_kp: float = 0.012
	pid_kd: float = 0.004
	correction_limit_px: float = 160.0

	obstacle_hold_band: float = 24.0
	obstacle_memory_frames: int = 18
	obstacle_clear_frames: int = 10
	obstacle_fade_factor: float = 0.85
	obstacle_max_correction_px: float = 35.0

	turn_top_ratio: float = 0.30
	turn_drop_ratio: float = 0.85

	record_orillas: bool = False
	record_output: str | None = None
	record_every_n: int = 6
	record_fps: float = 5.0


class PID:
	def __init__(self, kp: float, kd: float):
		self.kp = kp
		self.kd = kd
		self.prev_error = 0.0

	def compute(self, error: float) -> float:
		derivative = error - self.prev_error
		self.prev_error = error
		return (self.kp * error) + (self.kd * derivative)


class TurnDetector:
	def __init__(self, top_ratio: float = 0.30, drop_ratio: float = 0.85):
		self.top_ratio = top_ratio
		self.drop_ratio = drop_ratio
		self.prev_left = None
		self.prev_right = None
		self.kernel = np.ones((3, 3), np.uint8)

	def detect(self, frame_bgr: np.ndarray):
		h, w = frame_bgr.shape[:2]
		top_limit = max(1, int(h * self.top_ratio))
		roi = frame_bgr[:top_limit, :]

		split = w // 4
		left_roi = roi[:, :split]
		right_roi = roi[:, 3 * split :]

		left_hsv = cv2.cvtColor(left_roi, cv2.COLOR_BGR2HSV)
		right_hsv = cv2.cvtColor(right_roi, cv2.COLOR_BGR2HSV)

		left_mask = cv2.inRange(left_hsv, WOOD_LOWER, WOOD_UPPER)
		right_mask = cv2.inRange(right_hsv, WOOD_LOWER, WOOD_UPPER)

		left_mask = cv2.morphologyEx(left_mask, cv2.MORPH_OPEN, self.kernel)
		right_mask = cv2.morphologyEx(right_mask, cv2.MORPH_OPEN, self.kernel)

		left_ratio = cv2.countNonZero(left_mask) / max(1, left_mask.size)
		right_ratio = cv2.countNonZero(right_mask) / max(1, right_mask.size)

		left_drop = self.prev_left is not None and left_ratio < (self.prev_left * self.drop_ratio)
		right_drop = self.prev_right is not None and right_ratio < (self.prev_right * self.drop_ratio)

		self.prev_left = left_ratio
		self.prev_right = right_ratio

		if left_drop and not right_drop:
			return +1, left_ratio, right_ratio
		if right_drop and not left_drop:
			return -1, left_ratio, right_ratio
		return 0, left_ratio, right_ratio


class SerialLink:
	def __init__(self, port: str, baudrate: int):
		self.port = port
		self.baudrate = baudrate
		self.fd = None
		# Cola grande: si el hilo aún no drena (settle inicial) los primeros
		# mensajes NO se deben perder (maxsize=4 los tiraba en silencio ->
		# el ESP32 arrancaba sin comandos -> wall-PID de fallback = "el carro
		# avanza y no le entran datos de la Pi").
		self._queue = Queue(maxsize=256)
		self._last_rx = ""
		self._ready = threading.Event()   # se activa cuando el UART está listo
		self._thread = threading.Thread(target=self._run, daemon=True)
		self._thread.start()

	def _run(self):
		print(f"[SERIAL] Thread iniciado, abriendo {self.port}...", flush=True)
		try:
			import termios
			self.fd = os.open(self.port, os.O_RDWR | os.O_NOCTTY)
			iflag, oflag, cflag, lflag, ispeed, ospeed, cc = termios.tcgetattr(self.fd)

			# Modo raw completo — sin esto ICANON sigue activo y VMIN/VTIME
			# no aplican como se espera; ECHO puede reinyectar bytes recibidos
			# de vuelta al ESP32 y corromper el siguiente mensaje saliente.
			iflag &= ~(termios.IGNBRK | termios.BRKINT | termios.PARMRK | termios.ISTRIP |
			           termios.INLCR  | termios.IGNCR  | termios.ICRNL  | termios.IXON)
			oflag &= ~termios.OPOST
			lflag &= ~(termios.ECHO | termios.ECHONL | termios.ICANON |
			           termios.ISIG | termios.IEXTEN)
			cflag &= ~(termios.CSIZE | termios.PARENB | termios.CSTOPB)
			cflag |= termios.CS8 | termios.CLOCAL | termios.CREAD

			cc[termios.VMIN]  = 0
			cc[termios.VTIME] = 2

			ispeed = ospeed = termios.B115200

			termios.tcsetattr(self.fd, termios.TCSANOW,
			                   [iflag, oflag, cflag, lflag, ispeed, ospeed, cc])
			time.sleep(0.5)   # settle de línea / boot del ESP32
			try:
				termios.tcflush(self.fd, termios.TCIOFLUSH)   # descarta basura de arranque
			except Exception:
				pass
			self._ready.set()   # a partir de aquí open() deja de bloquear
			print(f"[SERIAL] UART abierto en {self.port} @ {self.baudrate}", flush=True)
			# El READY lo manda run() DESPUES del warmup de camara (ver
			# IntegratedRuntime.run / PPRuntime.run). Antes se enviaba aqui
			# "READY,pi=1" ~1s tras abrir el UART -- ANTES de que la vision
			# estuviera lista -- y el ESP32 salia de setup() y arrancaba a rodar
			# en wall-PID de fallback mientras la Pi seguia calentando la camara.
		except Exception as exc:
			self.fd = None
			print(f"[SERIAL] No se pudo abrir UART ({self.port}): {exc}", flush=True)
			return

		while True:
			try:
				line = self._queue.get(timeout=0.1)
			except Empty:
				continue
			if line is None:
				break
			try:
				os.write(self.fd, f"{line}\n".encode("utf-8"))
				print(f"[SERIAL] TX: {line}", flush=True)
			except Exception as e:
				print(f"[SERIAL] Error TX: {e}", flush=True)
			try:
				data = b""
				while True:
					chunk = os.read(self.fd, 1)
					if not chunk or chunk == b"\n":
						break
					data += chunk
				rx = data.decode("utf-8", errors="ignore").strip()
				if rx:
					self._last_rx = rx
					print(f"[SERIAL] RX: {rx}", flush=True)
			except Exception:
				pass

	def open(self, timeout: float = 5.0) -> bool:
		"""Bloquea hasta que el hilo del UART terminó el setup + settle.

		ANTES era un no-op: run() seguía al warmup y al loop mientras el hilo
		seguía en su sleep inicial, así que los primeros comandos V2 se
		encolaban y se perdían (cola de 4) y el ESP32 rodaba sin datos.
		"""
		ok = self._ready.wait(timeout=timeout)
		if not ok:
			print("[SERIAL] open() timeout: el UART no quedó listo a tiempo", flush=True)
		return ok

	def send_line(self, line: str):
		try:
			self._queue.put_nowait(line)
		except Full:
			pass

	def try_readline(self):
		rx = self._last_rx
		self._last_rx = ""
		return rx

	def close(self):
		try:
			self._queue.put_nowait(None)
		except Full:
			pass
		if self.fd is not None:
			try:
				os.close(self.fd)
			except Exception:
				pass
			self.fd = None


class IntegratedRuntime:
	def __init__(self, cfg: Config):
		self.cfg = cfg
		self.vision = Vision(cfg.cam_index)
		self.turn_detector = TurnDetector(cfg.turn_top_ratio, cfg.turn_drop_ratio)
		self.pid_obs = PID(cfg.pid_kp, cfg.pid_kd)
		self.serial_link = SerialLink(cfg.serial_port, cfg.baudrate)
		self.loop_count = 0
		self.persistencia_obstaculo = 0
		self.obstaculo_clear_frames = 0
		self.ultimo_color_obstaculo = None
		self.ultima_correccion_px = 0.0
		self.frame_grabber = None
		self.video_writer = None
		self.record_count = 0
		self.output_file = resolve_output_path(cfg.record_output) if cfg.record_orillas else None

		try:
			self.vision.cap.set(cv2.CAP_PROP_BUFFERSIZE, 1)
		except Exception:
			pass

	@staticmethod
	def largest_object(objects):
		if not objects:
			return None, None
		x, y, w, h = max(objects, key=lambda obj: obj[2] * obj[3])
		return (x, y, w, h), x + (w // 2)

	def obstacle_decision(self, positions, frame_width: int):
		red_obj, red_x = self.largest_object(positions.get("Red", []))
		green_obj, green_x = self.largest_object(positions.get("Green", []))

		if red_obj and green_obj:
			red_area = red_obj[2] * red_obj[3]
			green_area = green_obj[2] * green_obj[3]
			use_red = red_area >= green_area
		else:
			use_red = bool(red_obj)

		if use_red and red_obj:
			x = red_x
			error_px = float(self.cfg.red_target_px - x)
			color = "Red"
			mode = "avoid_red"
		elif green_obj:
			x = green_x
			error_px = float(self.cfg.green_target_px - x)
			color = "Green"
			mode = "avoid_green"
		else:
			return {
				"detected": False,
				"color": "None",
				"x": None,
				"error_px": 0.0,
				"vision_error_norm": 0.0,
				"mode": "no_obstacle",
				"priority": False,
				"memory_frames": 0,
			}

		if abs(error_px) > self.cfg.obstacle_hold_band:
			correction_px = self.pid_obs.compute(error_px)
			correction_px = max(-self.cfg.correction_limit_px, min(self.cfg.correction_limit_px, correction_px))
			self.ultima_correccion_px = correction_px
		else:
			correction_px = 0.0
			self.pid_obs.prev_error = 0.0
			self.ultima_correccion_px = 0.0

		self.persistencia_obstaculo = self.cfg.obstacle_memory_frames
		self.obstaculo_clear_frames = 0
		self.ultimo_color_obstaculo = color

		norm = -(correction_px / max(1.0, self.cfg.correction_limit_px))

		return {
			"detected": True,
			"color": color,
			"x": x,
			"error_px": error_px,
			"vision_error_norm": float(norm),
			"mode": mode,
			"priority": True,
			"memory_frames": self.persistencia_obstaculo,
		}

	def obstacle_memory_decision(self):
		if self.persistencia_obstaculo <= 0:
			self.obstaculo_clear_frames += 1
			return {
				"detected": False,
				"color": "None",
				"x": None,
				"error_px": 0.0,
				"vision_error_norm": 0.0,
				"mode": "no_obstacle",
				"priority": False,
				"memory_frames": 0,
			}

		self.persistencia_obstaculo -= 1
		self.obstaculo_clear_frames = 0

		correction_px = self.ultima_correccion_px * self.cfg.obstacle_fade_factor
		correction_px = max(-self.cfg.obstacle_max_correction_px, min(self.cfg.obstacle_max_correction_px, correction_px))
		self.ultima_correccion_px = correction_px

		if self.ultimo_color_obstaculo == "Red":
			mode = "memory_red"
		elif self.ultimo_color_obstaculo == "Green":
			mode = "memory_green"
		else:
			mode = "memory_unknown"

		norm = -(correction_px / max(1.0, self.cfg.correction_limit_px)) if self.ultimo_color_obstaculo else 0.0

		return {
			"detected": False,
			"color": self.ultimo_color_obstaculo or "None",
			"x": None,
			"error_px": 0.0,
			"vision_error_norm": norm,
			"mode": mode,
			"priority": True,
			"memory_frames": self.persistencia_obstaculo,
		}

	def build_serial_message(self, obs_info, turn_hint):
		if self.cfg.protocol == "legacy_x":
			if obs_info["detected"]:
				return str(int(obs_info["x"]))
			return str(self.cfg.neutral_x)

		obs = obs_info["vision_error_norm"]
		state = obs_info["mode"]
		prio = 1 if obs_info.get("priority", False) else 0
		mem = int(obs_info.get("memory_frames", 0))
		return f"V1,obs={obs:+.3f},turn={int(turn_hint)},state={state},prio={prio},mem={mem}"

	def annotate(self, frame, obs_info, turn_hint, left_ratio, right_ratio, serial_msg, fps=None):
		lines = [
			f"obs_color={obs_info['color']} x={obs_info['x']}",
			f"obs_err_px={obs_info['error_px']:.1f} obs_norm={obs_info['vision_error_norm']:+.3f}",
			f"turn_hint={turn_hint} wood_L={left_ratio:.3f} wood_R={right_ratio:.3f}",
			f"mode={obs_info['mode']} prio={int(obs_info.get('priority', False))} mem={obs_info.get('memory_frames', 0)}",
			f"serial={serial_msg}",
		]
		if fps is not None:
			lines.append(f"fps={fps:.1f}")
		y = 22
		for txt in lines:
			cv2.putText(frame, txt, (10, y), cv2.FONT_HERSHEY_SIMPLEX, 0.55, (255, 255, 255), 2)
			y += 22

	def start_capture(self):
		print(f"[CAM] cap.isOpened()={self.vision.cap.isOpened()} threaded={self.cfg.threaded_capture}", flush=True)
		if self.cfg.threaded_capture:
			self.frame_grabber = ThreadedFrameGrabber(self.vision.cap).start()
			print("[CAM] ThreadedFrameGrabber iniciado", flush=True)

	def read_frame(self):
		if self.frame_grabber is not None:
			return self.frame_grabber.read()
		return self.vision.cap.read()

	def maybe_record_frame(self, frame, fps):
		if not self.cfg.record_orillas:
			return
		self.record_count += 1
		if self.record_count % max(1, self.cfg.record_every_n) != 0:
			return

		if self.video_writer is None:
			out_fps = self.cfg.record_fps
			if fps > 0:
				out_fps = max(out_fps, fps / max(1, self.cfg.record_every_n))
			self.video_writer = AsyncVideoWriter(
				str(self.output_file),
				frame.shape[1],
				frame.shape[0],
				out_fps,
			).start()
			print(f"[INFO] Grabando orillas en {self.output_file}", flush=True)

		self.video_writer.write(frame.copy())

	def _write_cam_frame(self, frame):
		try:
			_, buf = cv2.imencode(".jpg", frame, [cv2.IMWRITE_JPEG_QUALITY, 65])
			with open(CAM_FRAME_PATH, "wb") as f:
				f.write(buf.tobytes())
		except Exception:
			pass

	def run(self, on_ready=None):
		self.serial_link.open()
		self.start_capture()

		# Descarta los primeros frames hasta que la exposicion de la camara se estabilice
		print(f"[INFO] Calentando camara ({self.cfg.warmup_frames} frames)...", flush=True)
		warmed = 0
		while warmed < self.cfg.warmup_frames:
			ret, _ = self.read_frame()
			if ret:
				warmed += 1
			else:
				time.sleep(0.01)
		print("[INFO] Camara estabilizada.", flush=True)

		# READY explicito: recien ahora que la camara esta lista y el pipeline
		# va a empezar a mandar control, avisar al ESP32 para que salga de
		# setup() y arranque motores. x3 por si se pierde el primer byte al
		# arrancar el UART. (Antes lo mandaba el hilo de SerialLink ~1s tras
		# abrir el UART, ANTES del warmup.)
		for _ in range(3):
			self.serial_link.send_line("READY")
			time.sleep(0.05)
		print("[INFO] READY enviado al ESP32.", flush=True)

		if on_ready is not None:
			on_ready()

		print("[INFO] Iniciando control WRO integrado. ESC para salir.", flush=True)

		last_fps_time = time.perf_counter()
		fps_count = 0
		fps = 0.0

		try:
			while True:
				ret, frame = self.read_frame()
				if not ret:
					print("[WARN] No frame capturado.", flush=True)
					time.sleep(0.01)
					continue

				self.loop_count += 1
				if self.loop_count % self.cfg.process_every_n != 0:
					time.sleep(0.001)
					continue

				fps_count += 1
				now = time.perf_counter()
				elapsed = now - last_fps_time
				if elapsed >= 1.0:
					fps = fps_count / elapsed
					fps_count = 0
					last_fps_time = now

				processed_frame, positions = self.vision.process_frame(frame)
				obs_now = self.obstacle_decision(positions, processed_frame.shape[1])
				if obs_now["detected"]:
					obs_info = obs_now
				else:
					self.pid_obs.prev_error = 0.0
					obs_info = self.obstacle_memory_decision()

				turn_hint_raw, left_ratio, right_ratio = self.turn_detector.detect(processed_frame)
				can_turn = (not obs_info.get("priority", False)) and (self.obstaculo_clear_frames >= self.cfg.obstacle_clear_frames)
				turn_hint = turn_hint_raw if can_turn else 0

				serial_msg = self.build_serial_message(obs_info, turn_hint)
				self.serial_link.send_line(serial_msg)
				serial_ack = self.serial_link.try_readline()

				if serial_ack:
					print(f"TX: {serial_msg} | RX: {serial_ack}", flush=True)
				else:
					print(f"TX: {serial_msg}", flush=True)

				if self.cfg.show_window:
					self.annotate(processed_frame, obs_info, turn_hint, left_ratio, right_ratio, serial_msg, fps=fps)
					cv2.imshow("WRO Runtime", processed_frame)
					if cv2.waitKey(1) & 0xFF == 27:
						break

				self.maybe_record_frame(processed_frame, fps)
				self._write_cam_frame(processed_frame)

		finally:
			if self.frame_grabber is not None:
				self.frame_grabber.stop()
			self.vision.cap.release()
			if self.video_writer is not None:
				self.video_writer.stop()
			cv2.destroyAllWindows()
			self.serial_link.close()


def parse_args():
	parser = argparse.ArgumentParser(description="Runtime integrado profesional para WRO Future Engineers.")
	parser.add_argument("--cam-index", type=int, default=0)
	parser.add_argument("--serial-port", type=str, default="/dev/ttyS0")
	parser.add_argument("--baudrate", type=int, default=115200)
	parser.add_argument("--protocol", choices=["signed", "legacy_x"], default="signed")
	parser.add_argument("--process-every", type=int, default=3)
	parser.add_argument("--threaded-capture", action="store_true")
	parser.add_argument("--no-threaded-capture", action="store_true")
	parser.add_argument("--record-orillas", action="store_true")
	parser.add_argument("--record-output", type=str, default=None)
	parser.add_argument("--record-every", type=int, default=6)
	parser.add_argument("--record-fps", type=float, default=5.0)
	parser.add_argument("--no-window", action="store_true")
	return parser.parse_args()
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

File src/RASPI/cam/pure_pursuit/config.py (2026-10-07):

"""
Parámetros de configuración del pipeline Pure Pursuit — WRO Future Engineers.

Hardware:
  Cámara  : Raspberry Pi Camera v2  (FOV ~62°, resolución proceso 640×480)
  Motor   : N20 DC 50:1 + etapa LEGO 2:1  → ratio total 100:1
  Servo   : SG90  (centro = 80°, límite mecánico ±35° efectivo en rueda)
  Chassis : 210×140×80 mm  |  batalla ~100 mm (estimado)
  ESP32   : recibe protocolo V2 por UART Serial2 (RX=17, TX=16) @ 115200
  Pi GPIO : LED en 27, botón arranque en 17

Ajusta primero CALIB_REAL_MM para que coincida con tu montaje de cámara,
luego corre calibrate.py para generar bev_calib.npz.
"""

import numpy as np
from pathlib import Path

# ─── Rutas ────────────────────────────────────────────────────────────────────
CALIB_FILE = Path(__file__).parent / "bev_calib.npz"

# ─── BEV — imagen de salida ───────────────────────────────────────────────────
BEV_W      = 400          # píxeles de ancho
BEV_H      = 400          # píxeles de alto
MM_PER_PX  = 2.0          # escala: 1px = 2 mm  →  400px = 800 mm de cobertura

# Posición del robot en la imagen BEV (eje trasero, centro horizontal)
ROBOT_BEV_X = BEV_W // 2   # 200
ROBOT_BEV_Y = BEV_H - 20   # 380

# ─── Puntos de calibración en el suelo (mm, relativo a eje delantero del robot) ──
# x_mm: lateral  (+ = derecha del robot)
# y_mm: distancia hacia adelante desde el eje delantero
#
# IMPORTANTE — por qué 9 puntos y no 4:
#   Una homografía con exactamente 4 puntos es un ajuste EXACTO: no hay forma
#   de detectar ni corregir un clic impreciso durante la calibración, y la
#   transformación se vuelve muy poco confiable fuera del área que cubren esos
#   4 puntos (extrapolación agresiva).  Con 9 puntos en grilla 3×3,
#   cv2.findHomography(..., RANSAC) puede promediar/filtrar el ruido de los
#   clics, y el área cubierta coincide con el rango real que usa
#   centerline.py (desde muy cerca del robot hasta ~550mm adelante).
#
#   Coloca marcadores físicos en el suelo en estas posiciones exactas y haz
#   clic en ellos EN ESTE MISMO ORDEN dentro de calibrate.py.
#
#          izquierda        centro         derecha
#   lejos:   P7 (-220,550)  P8 (0,550)   P9 (220,550)
#   media:   P4 (-150,300)  P5 (0,300)   P6 (150,300)
#   cerca:   P1  (-80, 80)  P2 (0, 80)   P3  (80, 80)
CALIB_REAL_MM = np.float32([
    [ -80.0,  80.0],   # P1: cerca-izquierda
    [   0.0,  80.0],   # P2: cerca-centro
    [  80.0,  80.0],   # P3: cerca-derecha
    [-150.0, 300.0],   # P4: media-izquierda
    [   0.0, 300.0],   # P5: media-centro
    [ 150.0, 300.0],   # P6: media-derecha
    [-220.0, 550.0],   # P7: lejos-izquierda
    [   0.0, 550.0],   # P8: lejos-centro
    [ 220.0, 550.0],   # P9: lejos-derecha
])

# Etiquetas legibles para cada punto (mismo orden que CALIB_REAL_MM)
CALIB_POINT_LABELS = [
    "P1 cerca-izq", "P2 cerca-centro", "P3 cerca-der",
    "P4 media-izq", "P5 media-centro", "P6 media-der",
    "P7 lejos-izq", "P8 lejos-centro", "P9 lejos-der",
]

# Umbral de error medio de reproyección (px BEV) a partir del cual calibrate.py
# advierte que probablemente un clic quedó mal puesto.
CALIB_MAX_MEAN_ERR_PX = 4.0

WALL_MARGIN_PX = 40

# ─── Color del piso (HSV) — tapete WRO: beige / madera cálida ────────────────
FLOOR_LOWER = np.array([0, 0, 140])
FLOOR_UPPER = np.array([35, 80, 255])

FLOOR_LOWER_BLUE = np.array([95, 50, 10])
FLOOR_UPPER_BLUE = np.array([150, 255, 220])
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

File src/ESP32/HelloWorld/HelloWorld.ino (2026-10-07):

/*
 * HelloWorld — prueba rápida de que la ESP32 sube código y habla por Serial.
 * Monitor serie a 115200. El LED integrado (GPIO 2 en la mayoría de las
 * DevKit) parpadea cada segundo.
 */

#define LED_PIN 2

void setup() {
  Serial.begin(115200);
  pinMode(LED_PIN, OUTPUT);
  delay(500);
  Serial.println("ESP32 viva");
}

void loop() {
  Serial.print("Hello world  t=");
  Serial.print(millis() / 1000);
  Serial.println(" s");

  digitalWrite(LED_PIN, !digitalRead(LED_PIN));
  delay(1000);
}

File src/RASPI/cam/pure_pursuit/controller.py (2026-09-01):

"""
Controlador geométrico Pure Pursuit operando en espacio de píxeles BEV.
...
"""

import math

from . import config as C


class PurePursuitController:
    """
    Controlador Pure Pursuit puro.
    Opera en coordenadas BEV donde el robot siempre apunta "hacia arriba"
    (Y decreciente = dirección de marcha).
    """

    def __init__(self):
        # Último steer_deg entregado por compute(), para el límite de slew.
        self._prev_steer_deg: float = 0.0

    @staticmethod
    def adaptive_lookahead(
        bev_obstacles: list[tuple[float, float, str]],
        robot_x: int = C.ROBOT_BEV_X,
        robot_y: int = C.ROBOT_BEV_Y,
    ) -> float:
        """
        Calcula el lookahead efectivo según qué tan cerca está el obstáculo
        más próximo al robot.

        Sin obstáculos, o con el más cercano lejos  -> LOOKAHEAD_MAX_PX
        (trayectoria suave, estable en recta/curvas normales).

        Con un obstáculo a <= LOOKAHEAD_OBS_NEAR_PX  -> LOOKAHEAD_MIN_PX
        (apunta a un punto cercano del path -> geometría exige steer más
        cerrado -> giro fuerte para esquivar de inmediato).

        Entre ambos umbrales, interpola linealmente para que la transición
        no sea un salto brusco de steer.
        """
        if not bev_obstacles:
            return C.LOOKAHEAD_MAX_PX

        # Distancia LONGITUDINAL (px por delante del eje), NO euclidiana. Con la
        # euclidiana, un obstáculo aún de lado (offset lateral grande) mantenía
        # nearest_d alto -> lookahead largo -> PP apuntaba lejos -> steer suave ->
        # el carro seguía DERECHO hasta tener el cono encima y ahí giraba tarde
        # (rozaba, orillas456). Con la longitudinal el lookahead se acorta cuando
        # el obstáculo se acerca DE FRENTE, sin importar cuánto lo tenga de lado.
        nearest_d = min(
            max(0.0, robot_y - oy) for ox, oy, _ in bev_obstacles
        )

        if nearest_d <= C.LOOKAHEAD_OBS_NEAR_PX:
            return C.LOOKAHEAD_MIN_PX
        if nearest_d >= C.LOOKAHEAD_OBS_FAR_PX:
            return C.LOOKAHEAD_MAX_PX

        t = (nearest_d - C.LOOKAHEAD_OBS_NEAR_PX) / (
            C.LOOKAHEAD_OBS_FAR_PX - C.LOOKAHEAD_OBS_NEAR_PX
        )
        return C.LOOKAHEAD_MIN_PX + t * (C.LOOKAHEAD_MAX_PX - C.LOOKAHEAD_MIN_PX)

    @staticmethod
    def _distance_steer_gain(bev_obstacles, robot_x, robot_y) -> float:
        if not bev_obstacles:
            return 1.0
        # LONGITUDINAL (px por delante del eje), no euclidiana — mismo motivo que
        # adaptive_lookahead: con la euclidiana un obstáculo aún de lado mantenía
        # nearest_d alto y el steer se atenuaba al 30% -> el carro iba derecho y
        # esquivaba tarde (rozaba, orillas456).
        nearest_d = min(max(0.0, robot_y - oy) for ox, oy, _ in bev_obstacles)
        if nearest_d <= C.STEER_DIST_GAIN_NEAR_PX:
            return 1.0
        if nearest_d >= C.STEER_DIST_GAIN_FAR_PX:
            return C.STEER_DIST_GAIN_MIN
        t = (nearest_d - C.STEER_DIST_GAIN_NEAR_PX) / (C.STEER_DIST_GAIN_FAR_PX - C.STEER_DIST_GAIN_NEAR_PX)
        return 1.0 - t * (1.0 - C.STEER_DIST_GAIN_MIN)

    def compute(
        self,
        path_points: list[tuple[int, int]],
        robot_x: int = C.ROBOT_BEV_X,
        robot_y: int = C.ROBOT_BEV_Y,
        lookahead_px: float = C.LOOKAHEAD_PX,
        bev_obstacles: list[tuple[float, float, str]] | None = None,
    ) -> tuple[float, tuple[float, float]]:
        if not path_points:
            return 0.0, (float(robot_x), float(robot_y))

        # NOTA: el sesgo de paso WRO (pasar a la derecha del rojo / izquierda
        # del verde) ya está horneado DENTRO de path_points por
        # centerline.py (_pass_side_cx + blend por best_w) -- este método NO
        # necesita buscar el punto "más lateral posible" para respetarlo.
        #
        # Antes, con bev_obstacles, se elegía el candidato con mayor
        # |offset_x| dentro del anillo de lookahead. Eso agarraba con la
        # misma prioridad un pico real de esquiva Y un pico de RUIDO de una
        # sola fila (p.ej. cuando el hueco libre más ancho de esa fila cae
        # del lado contrario al reglamentario y el "probe" que empuja cx
        # hacia el lado correcto tiene que recorrer mucho para salir de la
        # zona bloqueada -- ver _enforce_free_mask/blend en centerline.py).
        # Ese pico sobrevive el suavizado y termina siendo el target, dando
        # un steer pegado al límite mecánico y un lookahead visualmente
        # "colgado" del resto del path.
        #
        # Selección por distancia más cercana al lookahead ideal (igual que
        # la rama sin obstáculos) es robusta a ese ruido: un solo punto
        # desviado no gana solo por ser el más lateral, tiene que además
        # caer a la distancia correcta.
        if bev_obstacles:
            lo, hi = lookahead_px * 0.85, lookahead_px * 1.25
            candidates = [
                pt for pt in path_points
                if lo <= math.hypot(pt[0] - robot_x, pt[1] - robot_y) <= hi
            ]
            if candidates:
                target = min(
                    candidates,
                    key=lambda pt: abs(math.hypot(pt[0] - robot_x, pt[1] - robot_y) - lookahead_px),
                )
            else:
                target = path_points[-1]
                for pt in path_points:
                    if math.hypot(pt[0] - robot_x, pt[1] - robot_y) >= lookahead_px:
                        target = pt
                        break
        else:
            target = path_points[-1]
            for pt in path_points:
                dist = math.hypot(pt[0] - robot_x, pt[1] - robot_y)
                if dist >= lookahead_px:
                    target = pt
                    break

        dx = target[0] - robot_x
        dy = robot_y - target[1]
        ld = max(1.0, math.hypot(dx, dy))
        alpha = math.atan2(dx, dy)
        steer_rad = math.atan2(2.0 * C.WHEELBASE_PX * math.sin(alpha), ld)

        steer_deg = math.degrees(steer_rad)

        # ── NUEVO: atenúa el steer si el obstáculo más cercano aún está lejos ──
        if bev_obstacles:
            gain = self._distance_steer_gain(bev_obstacles, robot_x, robot_y)
            steer_deg *= gain

        steer_deg = max(-C.MAX_STEER_DEG, min(C.MAX_STEER_DEG, steer_deg))

        # ── Límite de slew: capa el cambio de steer entre frames procesados ──
        # Evita el latigazo (+0.56 -> +0.20 -> +0.79 -> -0.28 norm. visto en
        # pista). PP_STEER_SLEW_DEG <= 0 lo desactiva.
        slew = getattr(C, "PP_STEER_SLEW_DEG", 0.0)
        if slew > 0.0:
            lo = self._prev_steer_deg - slew
            hi = self._prev_steer_deg + slew
            steer_deg = max(lo, min(hi, steer_deg))
        self._prev_steer_deg = steer_deg

        return steer_deg, (float(target[0]), float(target[1]))

    def normalize(self, steer_deg: float) -> float:
        return max(-1.0, min(1.0, steer_deg / C.PP_STEER_GAIN))

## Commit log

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2026-08-27 Fix pasado nunca dispara
    BEHIND_PAD=40 ponia behind_y=420 pero BEV_H=400: la lata se salia por
    abajo del BEV antes de cruzar el umbral -> se descartaba en silencio,
    "pasado" 0 eventos en un run entero (prune=- siempre). Vuelto a 12
    (behind_y=392<400) + fallback en _prune(): salida por el borde inferior
    cerca de la columna del robot cuenta como PASADO.
    [config.py, obstacle_memory.py]
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2026-08-27 est=R es RECUPERANDO, no reversa
    El carro no tiene reversa. est=R = RECUPERANDO: corrige heading e va
    derecho, SIGUE avanzando (sin vision). Quitado el 'if estado==R: ds_px=0'
    que congelaba la memoria de mentira durante la recuperacion. El freno por
    giro (dheading) ya cubre "rota sin avanzar". Param estado se queda por
    compat pero ya no altera el avance.
    [obstacle_memory.py]
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2026-08-28 Rebase lateral por GIRO del IMU, no por x inferida
    run8 choco porque el rebase lateral dependia de que la x de la lata en el
    mapa cruzara x<192; la x oscila (rozo 195, reboto a 226) -> no cruzo ->
    gano "PASADO por y" a ang=-74 = RECUPERANDO tardisimo -> pared.
    Ahora _Obs guarda heading0 (heading del IMU al detectar la lata). El
    rebase lateral primario dispara cuando el carro roto >= OBS_MEM_LAT_TURN_DEG
    (35 deg) hacia el lado correcto desde heading0 (Red->der->heading baja;
    Green->izq->sube). Mide el giro REAL -> no le gana la condicion por
    distancia en un latiguazo. El cruce de x queda como OR de respaldo.
    MEMDBG ahora muestra x, ymin y giro acumulado de la lata mas cercana.
    [config.py, obstacle_memory.py]
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2026-08-28 Grabacion a MJPG/.avi + salida limpia en SIGTERM
    Los videos orillas*.mp4 quedaban ilegibles ("moov atom not found"):
    mp4v/.mp4 escribe el indice solo en release(), que no corre si el proceso
    muere sin cerrar (congelado / brownout / SIGKILL). Se perdieron 5 runs.
    - create_writer -> MJPG en .avi: frames JPEG independientes escritos
    progresivamente; el archivo queda reproducible hasta donde alcanzo a
    escribir aunque no cierre.
    - next_output_path -> .avi, indexa .mp4 y .avi para seguir la numeracion.
    - runtime_nuevo.main(): handler SIGTERM/SIGINT -> KeyboardInterrupt para
    que el try/finally de run() cierre el writer (systemctl stop/restart).
    [runtime_nuevo.py, wro_runtime.py]
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2026-08-28 SerialLink.open() bloquea hasta que el UART esta listo
    Bug de arranque: SerialLink.open() era no-op. El hilo del UART hacia
    os.open + termios + sleep(1.0) ANTES de drenar la cola, pero run()
    seguia de largo: warmup (instantaneo) -> READY -> loop mandando V2.
    Los primeros ~1.5s de comandos caian en una cola de 4 y se perdian;
    el ESP32, sin datos, rodaba en su fallback wall-PID = "el carro avanza
    en cuanto lo prendo y no le entran datos de la Pi".
    - _ready Event; _run() lo activa tras termios+settle(0.5)+tcflush.
    - open(timeout=5) espera ese Event.
    - cola 4 -> 256 (no perder comandos tempranos).
    - run(): espera ACK:READY del ESP32 (6 intentos) antes de entrar al loop.
    [runtime_nuevo.py, wro_runtime.py]
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2026-08-28 Centerline: fallback sin safe_mask usa max-clearance, no centro del hueco
    Post-esquiva el carro apunta a la pared y solo ve un triangulo de piso ->
    ningun segmento a >=WALL_MARGIN_PX -> el fallback tomaba el centro del
    hueco crudo -> el path se pegaba al borde de la pared (casi choca si
    RECUPERANDO entra tarde).
    Ahora el fallback toma, dentro del hueco crudo mas ancho, el pixel con
    mayor distanceTransform (mas lejos de cualquier pared). Se despega lo que
    la geometria permita, sin la urgencia dura de FRONT_WALL_URGENCY (que
    sigue desactivada por misfirear en esquinas).
    [centerline.py]
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2026-08-28 Esquiva mas fuerte: slew 12->22, LOOKAHEAD_MIN 70->55
    run16: el primer rojo se esquivo debil -> obs pico +0.857 (51deg) tras 5
    frames de rampa (slew a 8fps), y se aflojo a +0.55 con la lata aun cerca.
    - PP_STEER_SLEW_DEG 12->22: rampa 2x mas rapida, la esquiva compromete a
    tiempo. El latigazo por cambio de signo ya lo cubre lat-giro.
    - LOOKAHEAD_MIN_PX 70->55: la geometria pide steer mas cerrado close-in.
    El 70 era para frenar la saturacion que causaba el choque-pared, pero
    esa causa raiz (serial tardio + RECUPERANDO tardio) ya esta arreglada.
    [config.py]
2026-08-28 Revert "Esquiva mas fuerte: slew 12->22, LOOKAHEAD_MIN 70->55"
    This reverts commit a517126ab699c978510a21314f9ddf3e0e457e42.
    [config.py]
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2026-08-28 Pi: READY 3x rapido sin bloquear ~0.7s esperando ACK
    Reduce la ventana entre READY y el 1er V2, en la que el ESP32 rodaba en
    fallback wall-PID sin esquivar (~0.5s "avanza sin girar"). El fix real es
    lado ESP32 (piFirstV2Received: no rodar hasta el 1er V2).
    [runtime_nuevo.py]
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2026-08-28 Fix A: clamp del punto de paso de obstaculo al carril, no al sliver
    _pass_side_cx / _widest_free_segment elige el hueco libre por ANCHO. Con
    el cono cerca y pegado a un lado, agarraba el sliver de piso pegado a la
    pared (x lejisimos) en vez del hueco chico justo afuera del cono -> el
    path se curlaba a la pared, steer +30..45, el carro salia torcido de la
    esquiva -> detectarEsquina disparaba a media maniobra -> GIRANDO sumaba
    88 deg encima -> choque (run17 / frames del usuario).
    Ahora pass_cx clampeado a [iox +/- OBS_INFLATE_R, iox +/- (OBS_INFLATE_R
    + PASS_LANE_MARGIN_PX~30)]: pasa justo por fuera del cono, ~30px de aire,
    nunca se va a la pared. Solo toca _pass_side_cx.
    [centerline.py, config.py]
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2026-08-28 Revert "RECUPERANDO: disparo geometrico (x0,y0 + giro + v) como rama primaria"
    This reverts commit d906e97d2735a36f8422d47778f045ce28eb5c6b.
    [config.py, obstacle_memory.py, runtime_nuevo.py]
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2026-08-29 Más autoridad de steer a ~14fps + revierte d_pred x2
    Run en pista con el pipeline a ~14fps: la esquiva se sentía floja.
    Análisis de journalctl:
    - RECUPERANDO(lat-giro) disparaba a heading real ~-22° (objetivo 29)
    -> el d_pred x2 del commit anterior adelantaba ~7-9° y cortaba la
    esquiva corta. Revertido a x1 (a 14fps hay menos undershoot/frame).
    - obs pico por esquiva 0.3-0.7, casi nunca cerca del límite; el slew
    (6°/f) solo topó 4 de 707 frames -> no era el limitante.
    Cambios:
    - obstacle_memory d_pred: x2 -> x1 (revert)
    - OBS_MEM_LAT_TURN_DEG 29 -> 33 (deja rotar más antes de recuperar)
    - LOOKAHEAD_MIN_PX 70 -> 60 (geometría PP más cerrada con lata cerca)
    [config.py, obstacle_memory.py]
2026-08-29 RECUPERANDO entra tarde/corto a 14fps: OBS_MEM_LAT_TURN_DEG 33->22
    Log run 18:34 (thr=33): de las frames con PASADO, 201 dispararon por
    lat-x, 148 por PASADO(y), solo 9 por lat-giro. lat-giro dejó de ser el
    trigger primario: el lead predictivo d_pred usa |dheading/frame|, que a
    ~14fps es ~5° (vs ~12° a 8fps), así que 33 quedaba por encima del umbral
    alcanzable. RECUPERANDO entraba por lat-x a ~21° real con el carro ya
    regresando -> salía por headingOk en 2-3 frames.
    22 -> lat-giro dispara primero a ~17° real, a mitad de esquiva, con
    error de heading grande -> RECUPERANDO dura.
    [config.py]
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2026-08-29 RECUPERANDO: 3er trigger "geom" (posición inicial de la lata + giro real)
    OBS_MEM_LAT_TURN_MODE = "angle" | "geom" | "off" (reemplaza el flag
    OBS_MEM_LAT_TURN_ENABLED, que queda por compat).
    Problema del "angle" (umbral de giro fijo): ignora DÓNDE estaba la lata.
    22° despejan una lata muy lateral pero no una casi al frente -> dispara
    pronto o tarde. El "off" (solo rebase físico) entra tardísimo en
    esquivas de ángulo porque depende del avance frontal asumido, que no
    ocurre en un pivote (confirmado run 18:50: PASADO y a ang=-57).
    "geom": ancla dead-reckoning por lata (o.xr/o.yr) movida SOLO por
    ego-movimiento (giro real IMU + avance asumido·SPEED_SCALE, nunca
    re-anclada por deteccione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
    [config.py, obstacle_memory.py]
2026-08-29 Revertir a "angle" @ 35 — "geom" mató el rendimiento en pista
    Run 19:15: geom + la evaluación de _lat_pass en la rama BAJA_CONF
    disparaban RECUPERANDO en falso (pasado=1 a ang -3, +1, +8 = recto).
    Causa: el gate lateral de geom era abs(exr) >= CLEAR_PX -- una lata
    detectada YA descentrada lo cumple de entrada, solo faltaba algo de
    ruido de heading (dtheta>=8) para dispararlo.
    - OBS_MEM_LAT_TURN_MODE -> "angle" (estado que el usuario dejó a mano,
    DEG=35, rotación ON). geom queda como opción NO calibrada.
    - Rama BAJA_CONF vuelve a descartar en silencio (sin _lat_pass).
    - geom: gate lateral pasa a "separación GANADA desde la detección"
    (abs(exr)-abs(ex0) >= CLEAR_PX) para que una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
    [config.py, obstacle_memory.py]
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2026-08-29 geom v2: trigger de RECUPERANDO derivado de física (no de prueba-y-error)
    Modo "geom" reescrito con geometría cerrada + modelo de bicicleta:
    - Ancla o.xr/o.yr = posición inicial de la lata propagada por
    ego-movimiento: rotación = Δheading REAL del IMU, avance = arco
    s = R·Δθ con R = WHEELBASE/tan(steer) (usa el steer comandado, NO
    ROBOT_SPEED_MMS adivinado). runtime pasa steer_deg (frame anterior).
    - Signo de rotación del ancla CORREGIDO (phi_a = +dheading): verificado
    contra la forma cerrada. El mapa o.x/o.y mantiene su signo viejo
    (lo tapan las detecciones); el ancla es dead-reckoning puro.
    - Dispara si |X_r| >= CLEAR_PX ó Y_r <= AHEAD_MARGIN en el marco
    actual d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
    [config.py, obstacle_memory.py, runtime_nuevo.py]
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2026-08-29 centerline: arregla el "brinco hacia adentro" del path tras la lata
    Causa (identificada, no adivinada): _ramp_weight() decaía el peso de
    esquiva 1->0 sobre OBS_INFLATE_R (~39px = ~2-3 filas) apenas la fila
    libraba el borde superior del círculo de inflado. Con la lata en
    R(x=236,y=282) el cx del path saltaba 302->262->222->200 en ~42px de Y
    = gancho brusco hacia el centro que cruzaba el borde del inflado, luego
    esparcido a las filas del lookahead por _smooth_x.
    Asimétrico sin razón: entraba gradual (CENTERLINE_RAMP_PX ~200px),
    salía de golpe.
    Fix: salida sobre CENTERLINE_EXIT_RAMP_PX (=90px, ~4-5 filas) -> arco
    limpio. No se usa la rampa de entrada completa para no dejar el path
    sesgad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
    [centerline.py, config.py]
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2026-08-29 centerline: garantía de LADO — nunca trazar la ruta del lado contrario
    Causa (confirmada con [CLDBG], una sola lata rojo@204):
    y=285 pass=243 raw=243 lim=243 smo=243 enf=159 <<< SALTO
    Filas donde la lata cerca "unta" su color -> free_cx=None y no hay piso
    visible a la derecha. _pass_side_cx fabrica cx=ox+INFLATE_R=243 (no
    verificado). _enforce_free_mask ve 243 "bloqueado" y lo manda al único
    piso real de la fila, que está a la IZQUIERDA -> brinco hacia adentro.
    Premisa del usuario: físicamente SIEMPRE hay paso por el lado WRO
    obligado (la lata está en el corredor); que la cámara no lo vea NO es
    razón para rutear del otro lado.
    Fix: nueva _clamp_to_pass_side() corre AL FINAL (tr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
    [centerline.py, config.py]
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2026-08-29 centerline: CENTERLINE_COMMIT_W -> 0.12 (compromiso al lado correcto en toda la rampa)
    [config.py]
2026-08-29 centerline: clamp solo en el círculo real + RAMP_PX 200->130 (verde progresivo)
    Run 21:05 (video orillas404): centerline OK, rojo bien, pero el verde
    sigue arrancando fuerte de lejos (obs -0.48 con la lata a falta=+104px
    ~210mm) -> gira ~36°, pierde de vista el verde a media pista, se
    inclina, RECUPERANDO, y aparece adelante del bloque.
    Dos causas:
    1. _clamp_to_pass_side forzaba TODA fila con peso>=0.12 a la banda de
    paso del verde (x~69-99) aunque el círculo de inflado no llegue a
    esa fila (180px arriba) -> path jalado a la izquierda ~200px antes.
    Fix: clamp SOLO en filas dentro del círculo (|y-oy|<=INFLATE_R),
    empuja al borde exacto del círculo. Aproximación = blend grad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
    [centerline.py, config.py]
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2026-08-29 geom: ancla no se fija hasta y confiable + quita rama /lado
    Run 21:27 (orillas407): rojo cerca, esquiva arranca, y a 14° de giro
    PASADO(lat-geom/lado) Xr=-124 Yr=+212 -> RECUPERANDO -> choque.
    Causa: ymin=74. El ancla (x0,y0) se sembró de la PRIMERA detección del
    rojo, en el horizonte del BEV (y=74), donde cam->bev es basura. Todo el
    dead-reckoning arrancó de un punto inventado. Y la rama /lado dispara
    con |Xr|>=CLEAR sin checar Yr -> un ancla que dice "lata 212px adelante"
    disparó igual.
    Fixes:
    - _Obs.anchored: el ancla NO se fija hasta detectar la lata a
    y >= OBS_MEM_ANCHOR_MIN_Y (200). Antes _merge la re-siembra cada frame.
    - geom solo dispara si o.anchored.
    - Rama /lado (|Xr|>=C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
    [config.py, obstacle_memory.py]
2026-08-29 RECUPERANDO: trigger por ESTADO MEDIDO; retira el ancla geom
    El ancla dead-reckoning ("geom", 4 intentos: angle -> geom -> geom v2 ->
    SPEED_SCALE 1.0/0.35/0.60) integra IMU + modelo de bicicleta + velocidad
    no medida y deriva 200-400mm en 1-2s -> disparo prematuro (morro contra
    la lata) o tardio (57 deg de error). Cada intento quedaba sobre-ajustado
    a un run grabado y se rompia en el siguiente.
    Sustituto (solo Pi, .ino sin tocar -- RECUPERANDO sigue siendo solo-heading
    a proposito):
    - runtime_nuevo._measured_recup_trigger(): dispara pasado=1 cuando
    (1) hubo esquiva de verdad -- peso de esquiva de detect_centerline
    >= RECUP_MEAS_ARM_W en filas junto al eje -> _dodge_armed,
    _he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
    [centerline.py, config.py, runtime_nuevo.py]
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2026-08-29 RECUP medido: dispara ANTES (latch + solo distancia longitudinal)
    orillas412: RECUPERANDO disparó a herr=-64 (rojo) / +78 (verde) -- igual de
    tarde que el respaldo BEHIND_PAD. Dos causas:
    1) El "arm" re-armaba-y-retornaba cada frame mientras max_w_near >= ARM_W.
    Con conf~1.0 el peso seguía alto TODA la esquiva, así que el chequeo de
    disparo solo corría tras el prune de la lata. Fix: _dodge_armed es LATCH;
    el chequeo de disparo corre cada frame (aunque el heading siga creciendo).
    Guard _recup_can_arm: no re-arma hasta que el peso baje (esquiva nueva) ->
    no re-dispara en cadena sobre la misma lata mientras el ESP32 endereza.
    2) "blocking" usaba la x de la lata (o.x). Cuand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
    [config.py, runtime_nuevo.py]
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2026-08-29 RECUP medido: arreglo del heading_ref None (trigger muerto en orillas414)
    orillas414: [RECUP] armed=0 herr=+0 href=- toda la run -> measured NUNCA
    disparó; RECUPERANDO solo entró por BEHIND_PAD a ang=-70 (muy tarde) ->
    sobre-giro -> se clavó en la esquina junto al rojo.
    Causa: el trigger corría TAMBIÉN desarmado (hot-start). Ahí _last_heading
    es None (ACK=None), así que se armaba con _heading_ref=None. La siembra
    de _heading_ref estaba SOLO en el frame de armado y gateada por
    `not _dodge_armed` -> tras armarse sin heading quedaba None para siempre
    -> heading_err=0 -> |herr|>=HEADING_DEG nunca se cumplía. Y como quedaba
    "armado" sin ref, caía a esquiva-suave-ok y _recup_can_arm=Fals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
    [runtime_nuevo.py]
2026-08-29 RECUP medido: ahead_tol encoge con el giro (verde disparaba muy pronto)
    orillas415: el trigger YA funciona (rojo disparó measured a herr-47, bien).
    El verde disparó a herr+59 con la lata todavía en y=308 (72px ADELANTE) y
    x=233 (del lado hacia el que barre el morro al enderezar) -> RECUPERANDO
    enderezó el morro DENTRO del verde. Causa: la proyección BEV del verde
    (cono alto pegado al borde) lo clavó en y~255 mientras el carro giraba 33°,
    y al perder la detección saltó a 308; ahead_tol=90 fijo dio "despejado"
    con la lata aún 14cm adelante.
    Fix: ahead_tol ya no es fijo. Rampa por |heading_err|:
    |herr| <= HARD_LO(45) -> tol = AHEAD_TOL_PX(90) (rojo herr-47 ~igual)
    |herr| >= HA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
    [config.py, runtime_nuevo.py]
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2026-08-29 Esquiva: arreglo de raíz — el carro PIVOTEABA en vez de arquear
    Datos de orillas416 (log del rojo): obs se iba a +0.85..+0.93 (casi tope)
    en cuanto veía el cono; mientras obs>0.7 la 'y' del cono quedaba CLAVADA
    (~40 mm/s vs ~300 crucero) -> el carro no traslada, pivotea en el sitio.
    La esquiva nunca sale como arco -> luego RECUPERANDO entra a destiempo y
    es un desastre. A 7fps era fluido; la regresión NO fue el trigger.
    3 causas + fix:
    1. LOOKAHEAD_MIN_PX 60 -> 78. Con 60px (120mm) CUALQUIER offset lateral
    del path cerca del carro satura el steer (el comentario ya avisaba:
    "45px saturaba", "70px sin pegar el límite"). El 60 de 2026-08-28 quedó
    por debajo del piso seguro. 78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
    [config.py, obstacle_memory.py, runtime_nuevo.py]
2026-08-29 RECUP medido: no disparar al entrar a GIRANDO (herr=+89 espurio)
    orillas417 (por lo demás GRAN mejora: obs de esquiva ±0.4..0.7 no ±0.9,
    la y del cono avanza = arco no pivote, esquivó ambos, 12 giros completos).
    Pero ~vuelta 3: [RECUP] PASADO(medido) herr=+89 con nobs=0 en pleno giro.
    Causa: al entrar a GIRANDO el ESP32 hace anguloGyro=0 -> el heading del
    ACK salta ~90° -> heading_err (=_last_heading - _heading_ref sembrado en
    la recta) se dispara a ~+89 -> measured firaba con path "despejado"
    (sin cono) y clr>=3.
    Fix: al PRIMER est=G en el ACK (sin esperar los 2 frames de confirmación)
    se desarma la esquiva medida (_dodge_armed/_heading_ref/_recup_can_arm), y
    el trigger no corre si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
    [runtime_nuevo.py]
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2026-08-29 pasado=1 suprimido si la esquina es inminente (giro entraba tarde)
    orillas421 (confirma la hipótesis del usuario): en la esquiva del rojo/
    verde justo antes de una esquina, BEHIND_PAD dispara pasado=1 -> el ESP32
    entra a est=R (RECUPERANDO). En ese estado NO evalúa detectarEsquina()
    (vive en el case SIGUIENDO del switch) -> el giro entra ~0.5s tarde,
    DESPUÉS de que el ultrasónico ya no ve pared -> el carro pasa el punto de
    giro -> giro abierto/tarde -> se lleva el cono de la recta siguiente.
    Fix Pi-side: si line_info Orange near_y >= RECUP_SUPPRESS_NEAR_ORANGE_Y
    (285; robot en y=380 -> línea a <=~190mm), runtime pone _pasado_hold=0.
    El giro mismo endereza el heading; no hace falta RECU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
    [config.py, runtime_nuevo.py]
2026-08-31 Cono EXTERIOR pegado a la esquina: pasar recto y LUEGO girar
    Caso (reporte del usuario, HUD orillas424): la pista va a girar (naranja
    cerca) y en la boca de la esquina hay un cono cuyo lado de paso WRO es el
    CONTRARIO al giro (verde+giroD o rojo+giroI). classify_and_split() lo manda
    a "beyond" -> desaparece del plan -> prio=0/mem=0 -> el ESP32 gira contra el
    cono.
    Fix (solo Pi, NO toca PurePursuit.ino):
    - obstacle_memory.classify_and_split() acepta rescue_fn opcional: un cono que
    la clasificacion dejo en "beyond" se devuelve igual en `mine` sin tocar
    o.beyond (histeresis intacta).
    - runtime_nuevo arma rescue_fn cuando: naranja cerca + direccion conocida +
    cono exterior (not is_interio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
    [config.py, obstacle_memory.py, runtime_nuevo.py]
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2026-08-31 TurnDirectionTracker: inferir direccion SOLO durante la corrida
    Desarmado el pipeline corre igual pero el carro esta quieto y puede estar
    apuntando a una naranja que no es la del 1er giro -> latcheaba direccion
    espuria antes de arrancar (visto en idle: fija=R con el carro sin correr).
    - reset() del tracker en la transicion desarmado->armado.
    - update() recibe line=None y beyond=[] mientras !armed -> no forma guess.
    [runtime_nuevo.py]
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2026-09-01 Revert "SectionTurning: elimina la supresion de RECUPERANDO por linea naranja"
    This reverts commit 0914744b458aa870899522f809ac82d5baf37b14.
    [runtime_nuevo.py]
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2026-09-01 SectionTurning: fix clasificacion mine/beyond que ignoro un cono de la recta actual (orillas471)
    Bug: tras la maniobra, la naranja se fijo mal en la recta nueva (near_y
    saltando 157->318, fits de pendiente ~60deg basura, line[1]~+728). Un rojo
    de la recta ACTUAL quedo `beyond` desde el 1er frame; la histeresis TO_MINE(6)
    nunca lo solto y el carro lo embistio.
    Fix A - piso de cercania (CLASSIFY_FORCE_MINE_Y=290): un obstaculo con y-BEV
    >= 290 (behind_y de _prune = 345) esta casi bajo la nariz y NO puede ser de la
    siguiente recta. OrangeLineTracker.classify() y classify_and_split() lo fuerzan
    a "mia" ignorando la linea y rompen el latch `beyond` de una.
    Fix B - guard de ancho en X (LINE_FIT_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
    [config.py, corner_lines.py, obstacle_memory.py]
2026-09-01 SectionTurning: gate del piso de cercania por confianza + cooldown anti doble RECUPERANDO (orillas473)
    orillas473: tras esquivar el rojo, RECUPERANDO medido disparo (herr=-25) y el
    carro sobre-corrigio de -35 a +42 grados; encima el fantasma del rojo (memoria,
    conf 0.52, camR=0) cruzo behind_y y re-disparo pasado -> 2do RECUPERANDO justo
    sobre el verde -> el verde quedo al lado y se lo llevo. El verde estuvo bien
    clasificado (mia) todo el tiempo.
    Fix 2 - CLASSIFY_FORCE_MINE_MIN_CONF=0.65: el piso de cercania (Fix A de e2a949c)
    solo aplica si o.conf >= 0.65. Un fantasma de memoria extrapolado hasta y>=290
    ya no se fuerza a "mia" ni rompe el latch beyond. Se movio el piso enteramente
    a classi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
    [config.py, corner_lines.py, obstacle_memory.py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]
2026-09-02 SectionTurning: ventana de recuperacion tras RECUPERANDO medido (orillas475)
    orillas475 (mismo sintoma que 473): rojo esquivado -> RECUPERANDO medido
    (herr=-30) -> OrangeLineTracker re-adquiere sobre ruido y CONGELA near_y=308
    (line siempre None) durante ~2s -> el verde de MI recta (x=110, y=190-260)
    queda `beyond` por el fallback oy>near_y -> ignorado, y ademas fija turn_dir=L
    (el vere mal-clasificado esta a la izquierda del eje).
    Fix: tras un measured_pass, RECUP_RECOVERY_FRAMES=20 frames con
    _turn_recovery_frames activo -> no se llama classify_and_split (todo = mio) ni
    vota turn_dir, igual que la ventana post-giro (TURN_RECOVERY_FRAMES). Cubre la
    ventana donde aparece el verde. Cuando ex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
    [config.py, runtime_nuevo.py]
2026-09-02 SectionTurning: classify() exige ajuste de recta real, no solo near_y (orillas476)
    Root cause de orillas471/473/475/476: OrangeLineTracker.classify() sin
    stable["line"] caia a `oy > near_y`. Tras un RECUPERANDO el tracker re-adquiere
    sobre ruido (base del cono esquivado en hue naranja, reflejo), near_y se CONGELA
    en un valor CERCA y espurio con line=None durante ~2s, y todo cono "por encima"
    de ese near_y -- incluido el verde de MI recta -- queda `beyond` -> ignorado.
    La ventana RECUP_RECOVERY (9f2d1df) ayuda pero expira antes de que el verde
    importe (aparece ~1s despues del RECUP, visible ~2s).
    Fix: LINE_CLASSIFY_REQUIRE_FIT=True -> si line is None, classify() devuelve None
    (no opina -> cl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
    [config.py, corner_lines.py]
2026-09-02 SectionTurning: filtro de conos por pared frontal dF (no esquivar la recta siguiente)
    Realizacion del usuario (orillas477/478): al ver el verde de la recta actual,
    el carro tambien ve el rojo de la SIGUIENTE recta (por la esquina), lo mete a
    `mia` (sin ajuste de naranja valido -> classify=None -> mia) e intenta
    esquivarlo. Ese rojo lejano le hace de ancla/pivote -> el carro rota sin
    trasladar y no esquiva bien el verde.
    Fix: parsear dF del ACK (ultrasonico frontal del ESP, ya con mediana-de-5) y en
    runtime, tras classify_and_split, mover a `beyond` cualquier cono `mia` cuya
    distancia longitudinal en el BEV supere (dF*10 - DODGE_WALL_MARGIN_MM=100). Un
    cono en/pasando la pared de enfrente es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
    [config.py, runtime_nuevo.py]
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

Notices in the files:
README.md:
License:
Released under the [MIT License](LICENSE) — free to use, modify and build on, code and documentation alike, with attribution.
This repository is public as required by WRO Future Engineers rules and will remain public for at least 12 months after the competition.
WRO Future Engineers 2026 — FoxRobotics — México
